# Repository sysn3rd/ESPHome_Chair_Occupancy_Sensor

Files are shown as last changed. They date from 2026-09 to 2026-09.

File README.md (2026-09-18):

# Recliner Occupancy Sensor

A pressure pad under a recliner's seat cover tells Home Assistant when someone sits down and gets up. Home Assistant then reminds a caregiver to check on them, for a bathroom trip, a change, or a stretch, before they have been sitting too long. It works while the person is asleep and completely still, which motion sensors do not.

It was built for an elderly family member who uses a lift recliner and a walker and sometimes falls asleep in the chair, cared for by someone working from home in another room.

> **Safety note.** This is an assistive reminder tool. It is not a medical device, it does not detect falls, and it is not a substitute for supervision or professional care. It can fail: power cuts, WiFi outages, phone notification settings, Home Assistant problems, or a pad that has moved. It is designed to fail loudly where it can, with alerts when the sensor goes offline or the pad is disconnected, but the caregiver remains responsible. Test it before relying on it, and keep checking it.

Wiring diagram

## What it does

- **Reminders while seated,** at an interval you set, with **Handled** and **Snooze** buttons on the phone notification.
- **Escalation** to a critical alert, which breaks through silent mode, if a reminder is ignored. An event and an optional webhook let another system, such as an assistant or pager, escalate further.
- **Quiet hours:** no reminders overnight, so nobody is woken while the person sleeps in the chair.
- **Optional alerts** when the person gets up, and after a long sit (default 4 hours, daytime only).
- **Fails loudly:** an alert if the sensor goes offline, and another if the pad cable is cut or unplugged. Without that check, a broken pad would look like an empty chair and reminders would silently stop.
- **Rides out glitches:** a WiFi drop, reboot or pad fault keeps the last known state instead of cancelling a reminder.

## How it works

- **Pad:** a replacement chair alarm pad, the kind sold for caregiver monitors. It is a membrane switch: sitting presses two conductive layers together. Many pads run each layer out and back on two wires; this project uses the spare wire to detect a broken cable.
- **Board:** a Seeed XIAO ESP32S3 running ESPHome reads the pad on two pins, filters out shifting and leaning, and reports to Home Assistant over WiFi.
- **Home Assistant:** a generated package tracks when the person sat down and got up, decides when a check is due, and sends the notifications.
- **Case:** a 3D printed case holds the board, antenna and cable splices, with strain relief, attached to the chair's base with hook-and-loop.

## What you need

A Seeed XIAO ESP32S3 with its antenna, a chair sensor pad, two 1 kΩ resistors, a USB power adapter, a 3D printed case, basic soldering tools, and Home Assistant with the companion app. Full list: [docs/bom.md](docs/bom.md).

## Quick start

1. **Print** the case: [enclosure/](enclosure/README.md).
2. **Identify** your pad's wires: [docs/identify-your-pad.md](docs/identify-your-pad.md).
3. **Generate** your configuration: `python3 generate.py`. It asks for names, your phone's notify action and your preferred hours, then writes the ESPHome config, a secrets file with fresh encryption keys, the Home Assistant package, and an `INSTALL.md` written for your setup.
4. **Build:** [docs/build-guide.md](docs/build-guide.md). Flash and test the board before soldering, and test the pad on a breadboard before making it permanent.
5. **Install and test:** follow your generated `INSTALL.md`, then [docs/testing.md](docs/testing.md).

## Documentation

| Doc | Covers |
| --- | --- |
| [docs/bom.md](docs/bom.md) | Parts, tools and software |
| [docs/identify-your-pad.md](docs/identify-your-pad.md) | Finding the switch and check wires, hands-free measuring, other pad types |
| [docs/build-guide.md](docs/build-guide.md) | Step by step build and installation |
| [docs/testing.md](docs/testing.md) | Full test plan, alerting several phones |
| [docs/use-cases.md](docs/use-cases.md) | Features, optional alerts, dashboards, your own app |
| [docs/troubleshooting.md](docs/troubleshooting.md) | WiFi, stuck readings, Home Assistant issues |
| [enclosure/README.md](enclosure/README.md) | Printing and adjusting the case |

## Repository layout

```
generate.py          configuration generator (Python 3, standard library only)
templates/           ESPHome, Home Assistant and install guide templates
examples/            example answers for generate.py --config
enclosure/           OpenSCAD source and printable STLs
docs/                build, test and usage documentation
output/              your generated files (git-ignored, contains secrets)
```

## Status

Built and in use in one home, with one pad model: the Smart Caregiver 10 x 15 in replacement chair sensor pad. The hardware, firmware and in-chair behavior are tested. The Home Assistant package passes Home Assistant's own configuration check and matches the logic of the running installation. Reports from other pads and chairs are welcome.

## License

- **Code and configuration** (`generate.py`, `templates/`, `examples/`): [MIT](LICENSE).
- **Enclosure design, documentation and images** (`enclosure/`, `docs/`, this README): [CC BY-SA 4.0](LICENSE-CC-BY-SA-4.0.md).

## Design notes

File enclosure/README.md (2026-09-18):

# Enclosure

A small PLA case for the XIAO ESP32S3, its FPC antenna, and the pad cable splices, with strain relief for both cables. About 75 x 54 x 15 mm plus a 10 mm tab for the USB cable.

| File | What |
| --- | --- |
| `base.stl` | Base. Print open side up. |
| `lid.stl` | Lid. Already flipped: prints top face down. |
| `test.stl` | Just the USB-C end of the base, for a quick fit check of your USB cable's plug. |
| `recliner_enclosure.scad` | OpenSCAD source for all of the above. |

The STLs are the exact files printed and fitted for the tested build.

## Printing

- PLA, 0.2 mm layers, no supports.
- 3 walls and 20 % infill are plenty.
- About 25 g of filament for base and lid.
- Four M3 x 8 or x 10 self-tapping screws hold the lid. Drive them until just snug.

## What is inside

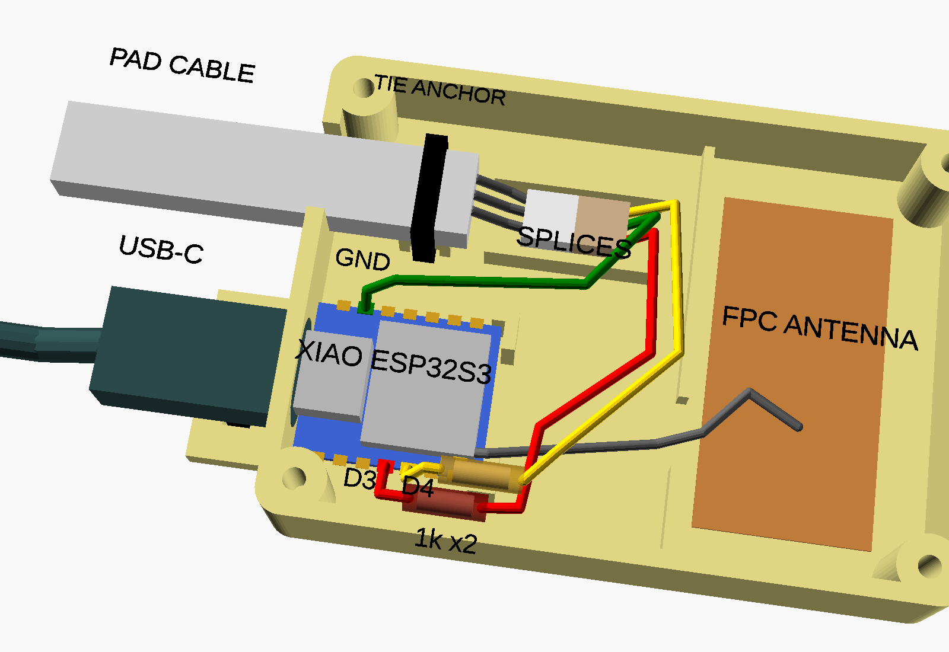
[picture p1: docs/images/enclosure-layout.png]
Inside the enclosure


- **Board bay:** the XIAO sits on a raised platform on foam tape, located by two corner stops at the antenna end, with room along both edges for wires.
- **USB-C:** a 12.5 x 7.5 mm opening sized for a cable's plug overmold, and an outside tab with two zip tie slots so a tug on the cable never reaches the board.
- **Pad cable:** an open-top notch in the end wall. Inside, a zip tie through a tunnel under a raised block grips the cable jacket, and a tongue on the lid presses lightly on the cable.
- **Splice area:** between two low rails, room for the three soldered splices (or a JST connector pair, if you prefer one).
- **Antenna bay:** the FPC antenna sticks flat to the floor, past a low divider with a gap for the coax.

## Adjusting

Open `recliner_enclosure.scad` in OpenSCAD. The `part` variable picks the view:

| `part` | Shows |
| --- | --- |
| `layout` (default) | The base with stand-in board, antenna, cables and wiring. Preview only (F5); rendering (F6) falls back to the base. |
| `assembly` | Base and lid together |
| `base`, `lid`, `test` | The printable parts |

Export a part from the command line:

```
openscad -D 'part="base"' -o base.stl recliner_enclosure.scad
```

Values you are most likely to change:

| Variable | Default | When to change |
| --- | --- | --- |
| `cable_w`, `cable_t` | 10, 5 mm | Your pad cable's width and thickness. Measure it. If only the lid's grip is wrong, change `cable_t` and reprint just the lid. |
| `cable_squeeze` | 0.3 mm | How hard the lid tongue presses on the cable. Keep it light; a crushed flat cable can short its conductors. |
| `usb_center_above_pcb_bottom`, `platform_h` | 2.7, 2.5 mm | If your USB plug does not line up with the opening. Print `test.stl` to check. |

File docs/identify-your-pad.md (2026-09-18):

# Identify your pad's wires

Do this before soldering anything. Guessing the wire pair is the most common way to end up with a sensor that reads "occupied" forever.

## What you are looking for

Chair alarm pads are membrane switches: two conductive layers that touch when someone sits. Many pads, including the tested one, run **each layer out and back on two wires** so the original alarm can check the cable is intact. That gives four wires in two loops:

| Pair | Empty pad | Someone sitting |
| --- | --- | --- |
| Both ends of layer A (tested pad: red + black) | about 0 Ω, always | about 0 Ω |
| Both ends of layer B (tested pad: green + yellow) | about 0 Ω, always | about 0 Ω |
| One wire from A, one from B (any cross pair) | open | low, tens of ohms up to a few kΩ |

The switch is the **cross pair**. The two same-layer pairs are not switches at all: they are shorts. Wiring one across D3 and GND ties the pin to ground permanently.

Wiring diagram

## Measure hands-free

Holding meter probes on thin stranded wire gives false readings: a probe that slips reads "open", which looks exactly like an open switch. Removing your hands from the measurement fixes that.

1. Cut off the pad's plug. Strip about 5 mm of each wire and twist the strands.
2. Solder or twist each pad wire onto a short solid-core jumper, and plug each into its own row of a breadboard.
3. Wrap a solid-core jumper tightly around each meter probe tip and plug those into the rows you want to measure.
4. Meter on resistance. A manual-range meter on the 20k range works well; `1` or `OL` means open.

Now measure every pair (four wires make six pairs), first with the pad empty, then pressing firmly on it or sitting on it. Write both readings down.

## Reading the results

- **Two pairs at 0 Ω empty, cross pairs open empty and low when pressed:** the looped pad above. Wire one end of layer A to D3 and the other end of layer B to D4, each through a 1 kΩ resistor, and one end of layer B to GND. D4 is the cable-break check. The fourth wire is unused.
- **Only two wires, open empty and low when pressed:** a plain switch pad. Wire one to D3 (through the resistor) and the other to GND. Then connect **D4 directly to GND** with a short wire, or the cable check will report a problem forever. Cable-break detection is not available with this pad.
- **A cross pair is low when empty and opens when pressed:** a normally closed pad. It will work, but in the generated ESPHome file change `inverted: true` to `inverted: false` under the `Pad Raw` pin.
- **Pressed reading above about 10 kΩ:** the pad is too resistive for the board's internal pull-up to read reliably. It needs a different design (an analog threshold), which this project does not cover yet.
- **Nothing changes when pressed:** press harder, or across a wider area. Membrane pads need real weight. If still nothing, the pad may be faulty.

## Tested pad, for reference

Replacement 10in x 15in Chair Sensor Pad by Smart Caregiver, UPC 812293010372 ([Amazon B01N0P2J6X](https://www.amazon.com/dp/B01N0P2J6X)), made for their TL-2100 series monitors:

- Red + black and green + yellow are the two loops.
- Red to green reads about 40 to 60 Ω under hand pressure, open when empty.

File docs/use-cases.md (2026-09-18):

# Use cases

What the generated Home Assistant package does day to day, and how to turn on the optional parts. Entity IDs use `<person>` and `<chair>` as in [testing.md](testing.md); your `INSTALL.md` has the real ones.

## Entities

| Entity | Meaning |
| --- | --- |
| `binary_sensor.<chair>_occupied` | Device reading, filtered: on shortly after sitting, off 90 s (default) after standing. Unavailable while the device is offline. |
| `binary_sensor.<chair>_pad_cable` | Problem sensor: on when the pad cable is cut or the pad unplugged. |
| `binary_sensor.<person>_seated` | Like Occupied, but holds the last known state through outages and pad faults. Use this for timing and dashboards. |
| `sensor.<person>_sat_down` | When the person last sat down. |
| `sensor.<person>_last_got_up` | When the person last got up. |
| `sensor.<person>_minutes_seated` | Minutes in the chair this sitting, 0 when up. |
| `binary_sensor.<person>_check_due` | On when a check is due. Drives the reminders. |

The timestamps survive Home Assistant restarts and device reboots. After an outage they only update if the person's state changed while the device was offline, and then they show the reconnect time.

## Reminders (main feature)

While seated, a reminder arrives each time the interval passes since sitting down or since the last **Handled**. Ignored reminders escalate to a critical alert and a `recliner_escalation` event after the escalation delay, and repeat until handled or the person gets up. Nothing fires outside your active hours; at the end of the day an active reminder clears, and next morning it starts again if still due.

Turn on with `<person> reminders enabled`. Set `<person> reminder interval` and `<person> escalation delay` to the care plan first: both start at 1 minute after installation.

**Escalating beyond the phone:** another automation, assistant or pager can listen for `recliner_escalation` (with `event_data.person`) and stand down on `recliner_escalation_resolved`. If you gave `generate.py` a webhook URL, the same escalation and stand-down are also sent there as JSON: `{"person": ..., "event": "escalation" or "resolved", "message": ...}`.

## Alert when they get up

A notification each time the person leaves the chair, for example to go and help with a walker. Turn on `<person> got up alerts enabled`.

It arrives after the off delay (default 90 s), which stops leaning forward or shifting from counting. A sensor outage or a broken pad never triggers it.

To test: sit for at least the on delay, stand, and wait for the notification. Then sit, lean forward for a few seconds, and sit back: nothing should arrive.

If the delay is too long, watch a few days of Pad Raw history to see how long shifts actually last, then re-run `generate.py` with a smaller `delayed_off` and reinstall the firmware over WiFi. This also makes reminders clear sooner.

## Time since up

No setup needed. Add `sensor.<person>_minutes_seated`, `sensor.<person>_sat_down` and `sensor.<person>_last_got_up` to a dashboard. Home Assistant shows timestamps as relative times, like "Sat down 2 hours ago".

## Long sit alert, daytime only

One notification per sitting when the person has not got up for the hours you chose (default 4), only within active hours. If a sitting passes the threshold overnight, the alert arrives when active hours start. Turn on `<person> <N> hour seated alert enabled`.

To test without waiting hours: in the generated package, temporarily change both `above:` values in the long sit automation to `1`, reload automations, sit for 2 minutes, and confirm the alert. Then change them back.

## Dashboard

Settings > Dashboards > Add dashboard, then add cards. Tile cards show state as text as well as color.

```yaml
type: vertical-stack
cards:
  - type: tile
    entity: binary_sensor.<person>_seated
    name: In the chair
  - type: tile
    entity: sensor.<person>_minutes_seated
    name: Minutes seated
  - type: tile
    entity: sensor.<person>_last_got_up
    name: Last got up
  - type: tile
    entity: binary_sensor.<chair>_pad_cable
    name: Pad
  - type: history-graph
    title: Today
    hours_to_show: 24
    entities:
      - entity: binary_sensor.<person>_seated
```

Also useful: a Logbook card filtered to `binary_sensor.<chair>_occupied` for a text list of sit and stand times, the device's WiFi Signal sensor, and tiles for the enable toggles.

## Daily totals

The History stats integration (Settings > Devices & services > Add integration > History stats) can count time seated today (type: time, entity `binary_sensor.<person>_seated`, state on) and times up today (type: count, entity `binary_sensor.<chair>_occupied`, state off). Start `{{ today_at() }}`, end `{{ now() }}`. The count includes the device reconnecting while the person is up, so treat it as approximate.

## Longer history

Home Assistant keeps detailed history for 10 days by default. Raise it in `configuration.yaml`:

```yaml
recorder:
  purge_keep_days: 60
```

`sensor.<person>_minutes_seated` also records long-term statistics, which a Statistics graph card can show indefinitely.

## Your own dashboard app

Read from Home Assistant rather than the device: it has the derived sensors, and the device's API is meant for Home Assistant.

- **Live state:** the WebSocket API, for example with the `home-assistant-js-websocket` package (`createLongLivedTokenAuth`, `createConnection`, `subscribeEntities`).
- **History:** `GET /api/history/period/<start>?filter_entity_id=binary_sensor.<person>_seated&minimal_response&no_attributes` with `Authorization: Bearer <token>`.
- **Token:** your profile > Security > Long-lived access tokens. A browser app calling Home Assistant directly needs its origin in `http: cors_allowed_origins`, and exposes the token in page code; a small local backend that holds the token is safer.
- **Accessibility:** show state in words ("In the chair, 2 h 15 min"), not color alone; announce changes with an `aria-live="polite"` region; make an offline sensor obvious ("Sensor offline, last known: seated").

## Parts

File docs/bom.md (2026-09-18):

# Bill of materials

Quantities are for one chair. Nothing here is exotic; the only part that varies between builds is the pad, so read [identify-your-pad.md](identify-your-pad.md) before buying anything else if you already have one.

## Electronics

| Part | Qty | Notes |
| --- | --- | --- |
| Seeed Studio XIAO ESP32S3 | 1 | The plain version, not the Sense. It ships with the U.FL FPC antenna, which is **required**: without it the board sees the network at about -90 dBm and cannot connect. Consider buying 2; the castellated pads lift if reworked too often. |
| Chair sensor pad, corded, 10 x 15 in | 1 | **Tested:** Replacement 10in x 15in Chair Sensor Pad by Smart Caregiver, UPC 812293010372 ([Amazon B01N0P2J6X](https://www.amazon.com/dp/B01N0P2J6X)). A replacement pad for their TL-2100 series monitors, with a 4-wire modular plug. Other brands usually work, but wire colors and layout vary: see [identify-your-pad.md](identify-your-pad.md). |
| 1 kΩ resistor, 1/4 W | 2 | One on the switch wire (D3) and one on the check wire (D4), protecting the pins from static on the long pad cable. |
| USB-C cable | 1 | Must carry data for the first flash. After that any cable works. |
| 5 V USB power adapter, 1 A or more | 1 | Wall power only. WiFi drains a battery in under a day. |
| Stranded hookup wire, 24 to 26 AWG | about 30 cm each of 3 colors | Match the pad colors if you can; it makes checking easier. |
| Heat shrink tubing | assorted, 2 to 5 mm | For every splice and over both resistors. |

## Enclosure and mounting

| Part | Qty | Notes |
| --- | --- | --- |
| PLA filament | about 25 g | Base and lid. See [../enclosure/README.md](../enclosure/README.md). |
| M3 self-tapping screws, 8 or 10 mm | 4 | Lid to base. Drive until just snug; PLA strips easily. |
| Double-sided foam tape | small piece | Holds the board on its platform. |
| Zip ties, 2.5 mm wide | 3 | One anchors the pad cable inside the case, two strain relieve the USB cable outside. |
| Adhesive hook-and-loop (Velcro) | about 5 x 7 cm | Mounts the case to the chair's base fabric. |

## Tools

| Tool | Why |
| --- | --- |
| 3D printer, or a print service | Enclosure |
| Soldering iron and solder, flux | Board and splices. Chisel tip, about 320 °C for leaded solder, 350 to 370 °C for lead-free. |
| Multimeter | Identifying the pad's wires |
| Solderless breadboard and solid-core jumper wires | Hands-free measuring and a no-solder test before the permanent build. Strongly recommended. |
| Helping hands or alligator clips | Hold work steady while soldering |
| Wire strippers, flush cutters | General |
| Computer with a USB port | First flash |

## Software

| Software | Notes |
| --- | --- |
| Home Assistant | With the companion app on each caregiver's phone |
| ESPHome | ESPHome Device Builder (add-on or desktop) or the `esphome` command line tool |
| Python 3.8 or newer | Runs `generate.py`. Standard library only, nothing to install. |

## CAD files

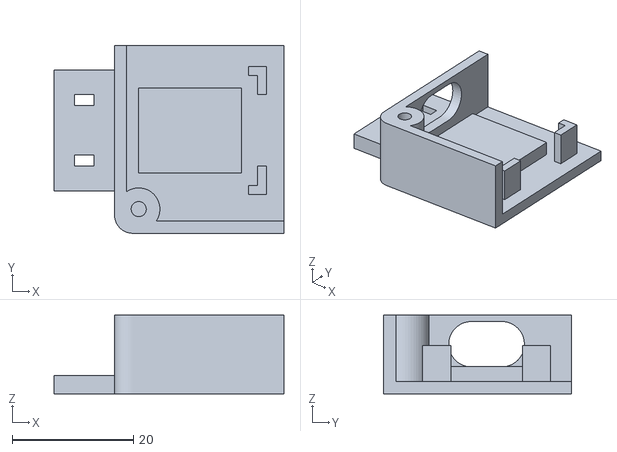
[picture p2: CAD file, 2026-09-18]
enclosure/test.stl
38.0 x 31.0 x 13.0

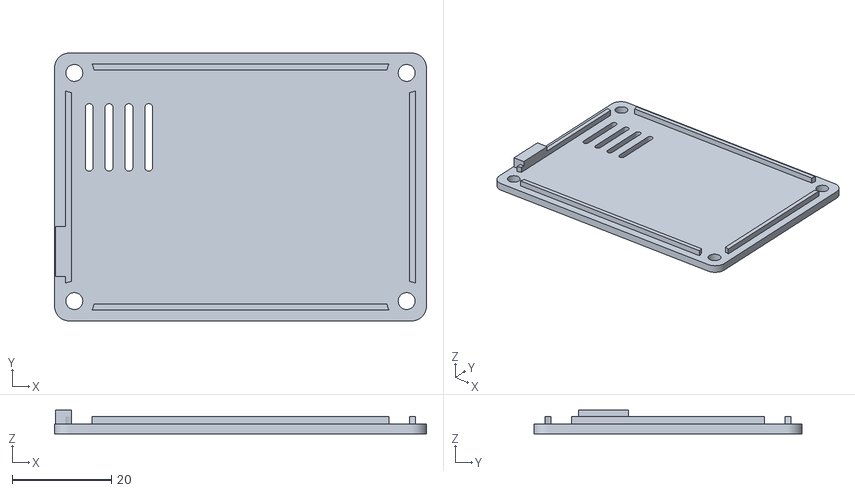
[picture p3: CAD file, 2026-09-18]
enclosure/lid.stl
75.0 x 54.0 x 4.80

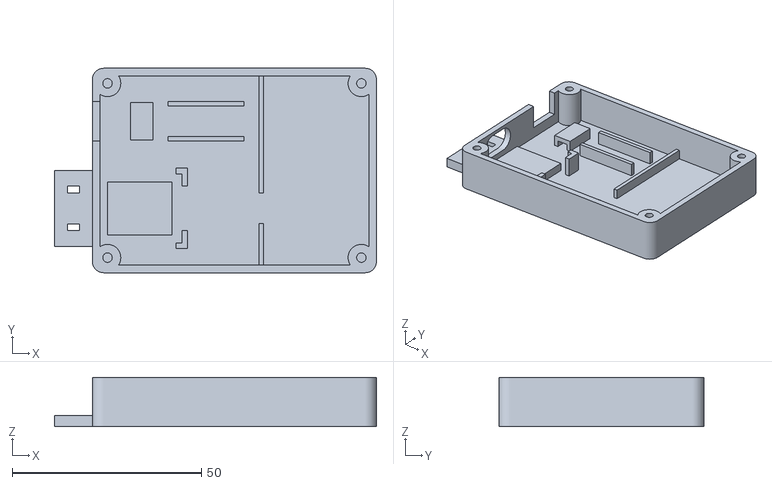
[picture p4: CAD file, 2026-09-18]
enclosure/base.stl
85.0 x 54.0 x 13.0

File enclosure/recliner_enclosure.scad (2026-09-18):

// Recliner occupancy sensor enclosure
// Seeed XIAO ESP32S3 + FPC antenna + pad cable splices (or an optional JST pair)
// License: CC BY-SA 4.0 (see LICENSE-CC-BY-SA-4.0.md)
//
// Render one part at a time:
//   openscad -D 'part="base"' -o base.stl recliner_enclosure.scad
//   openscad -D 'part="lid"'  -o lid.stl  recliner_enclosure.scad
//   openscad -D 'part="test"' -o test.stl recliner_enclosure.scad   (USB-C fit test)
//
// part="layout" shows the base with approximate stand-in parts (board, antenna,
// cables, JST, zip ties, wiring). Use Preview (F5); the stand-ins are not printed.
//
// Coordinates: origin is the inside corner of the floor at the USB-C end.
// X runs from the USB-C wall toward the antenna bay, Y across, Z up.

part = "layout"; // layout | assembly | base | lid | test
show_lid = false;     // layout view: draw the lid as a transparent ghost
show_labels = true;   // layout view: floating text labels

$fn = 48;
eps = 0.01;

// ---------- Shell ----------
wall  = 2.0;
floor_t = 2.0;
lid_t = 2.0;
in_L = 71;   // interior length (X)
in_W = 50;   // interior width (Y)
in_H = 11;   // interior height, floor top to lid underside
corner_r = 3;

// ---------- XIAO ESP32S3 ----------
pcb_L = 21.0;
pcb_W = 17.8;
pcb_gap_front = 0.3;   // PCB edge to inside of USB wall
pcb_y = 15;            // PCB centerline in Y
platform_h = 2.5;      // raised pad the board sits on
tape_t = 1.0;          // double-sided foam tape under the board
locator_h = 2.5;       // how far corner locators rise above the board bottom

// USB-C opening, sized for a cable overmold, not the bare receptacle
usb_open_w = 12.5;
usb_open_h = 7.5;
usb_center_above_pcb_bottom = 2.7;  // from the Seeed case: port sits ~1.1 above floor, ~3.2 tall

// ---------- Pad cable and JST ----------
cable_w = 10.0;        // measure with calipers
cable_t = 5.0;
cable_y = 38;          // cable centerline in Y
cable_clear = 0.4;     // added to each notch dimension
cable_squeeze = 0.3;   // lid tongue presses this far into the jacket
anchor_x = 8;          // zip tie anchor block start
anchor_len = 6;
anchor_h = 3.5;        // cable rides on top of this block
tie_tunnel_w = 3.5;    // for 2.5 mm zip ties
tie_tunnel_h = 2.0;

jst_gap = 8.0;         // space between cradle rails: holds the three soldered splices or a JST pair
jst_x0 = 18;
jst_len = 20;
jst_rail_t = 1.2;
jst_rail_h = 4;

// ---------- Antenna bay ----------
rib_x = 42;
rib_t = 1.2;
rib_h = 3;
rib_gap = 8;           // U.FL cable passes here, centered on pcb_y

// ---------- Lid screws (M3 self-tapping into PLA) ----------
boss_d = 7;
boss_inset = 2;        // boss center from inside corner
pilot_d = 2.5;
screw_clear_d = 3.4;
lip_h = 1.5;
lip_t = 1.2;
lip_clear = 0.25;

// ---------- USB cable tie tab ----------
tab_len = 10;
tab_w = 20;
tab_t = 3;
tie_slot = [3.2, 1.8];  // X (band width), Y (band thickness)
tie_slot_offset = 5;    // slot centers from the USB centerline
tie_groove_d = 1.5;

// ---------- Helpers ----------
module rounded_box(size, r) {
    hull() for (x = [r, size[0] - r], y = [r, size[1] - r])
        translate([x, y, 0]) cylinder(r = r, h = size[2]);
}

boss_pts = [[boss_inset, boss_inset], [boss_inset, in_W - boss_inset],
            [in_L - boss_inset, boss_inset], [in_L - boss_inset, in_W - boss_inset]];

usb_z = platform_h + tape_t + usb_center_above_pcb_bottom;
notch_bottom = anchor_h;
tongue_bottom = anchor_h + cable_t - cable_squeeze;

// ---------- Base ----------
module shell() {
    difference() {
        translate([-wall, -wall, -floor_t])
            rounded_box([in_L + 2 * wall, in_W + 2 * wall, floor_t + in_H], corner_r);
        cube([in_L, in_W, in_H + eps]);
    }
}

module usb_cut() {
    translate([-wall - eps, pcb_y, usb_z])
        rotate([0, 90, 0])
        hull() for (dy = [-(usb_open_w - usb_open_h) / 2, (usb_open_w - usb_open_h) / 2])
            translate([0, dy, 0]) cylinder(d = usb_open_h, h = wall + 2 * eps);
}

module cable_notch() {
    translate([-wall - eps, cable_y - (cable_w + cable_clear) / 2, notch_bottom])
        cube([wall + 2 * eps, cable_w + cable_clear, in_H]);
}

module board_platform() {
    translate([2, pcb_y - 7, 0]) cube([pcb_L - 4, 14, platform_h]);
}

module box2(a, b) {  // cube between two corner points
    translate([min(a[0], b[0]), min(a[1], b[1]), min(a[2], b[2])])
        cube([abs(b[0] - a[0]), abs(b[1] - a[1]), abs(b[2] - a[2])]);
}

// L-shaped stops at the two corners away from the USB-C port.
// They touch only the last ~1.5 mm of each long edge, clear of the castellated pads.
module board_locators() {
    top = platform_h + tape_t + locator_h;
    back = pcb_gap_front + pcb_L + 0.3;
    for (s = [-1, 1]) {
        edge = pcb_y + s * (pcb_W / 2 + 0.2);
        box2([back, pcb_y + s * (pcb_W / 2 - 3), 0], [back + 1.5, edge + s * 1.5, top]);
        box2([back - 1.5, edge, 0], [back + 1.5, edge + s * 1.5, top]);
    }
}

module tie_anchor() {
    difference() {
        translate([anchor_x, cable_y - cable_w / 2, 0])
            cube([anchor_len, cable_w, anchor_h]);
        translate([anchor_x + (anchor_len - tie_tunnel_w) / 2, cable_y - cable_w / 2 - eps, -eps])
            cube([tie_tunnel_w, cable_w + 2 * eps, tie_tunnel_h + eps]);
    }
}

module jst_cradle() {
    for (s = [-1, 1])
        translate([jst_x0, cable_y + s * (jst_gap / 2) + (s > 0 ? 0 : -jst_rail_t), 0])
            cube([jst_len, jst_rail_t, jst_rail_h]);
}

module antenna_rib() {
    difference() {
        translate([rib_x, 0, 0]) cube([rib_t, in_W, rib_h]);
        translate([rib_x - eps, pcb_y - rib_gap / 2, -eps]) cube([rib_t + 2 * eps, rib_gap, rib_h + 2 * eps]);
    }
}

module bosses() {
    for (p = boss_pts) translate([p[0], p[1], 0])
        difference() {
            cylinder(d = boss_d, h = in_H);
            translate([0, 0, 2]) cylinder(d = pilot_d, h = in_H);
        }
}

// Floor-level tab outside the USB-C wall. Zip tie the power cable here so a tug
// never reaches the XIAO's USB-C receptacle.
module usb_tie_tab() {
    slot_x = -wall - tab_len / 2;
    difference() {
        translate([-wall - tab_len, pcb_y - tab_w / 2, -floor_t])
            cube([tab_len + eps, tab_w, tab_t]);
        for (s = [-1, 1])
            translate([slot_x - tie_slot[0] / 2, pcb_y + s * tie_slot_offset - tie_slot[1] / 2, -floor_t - eps])
                cube([tie_slot[0], tie_slot[1], tab_t + 2 * eps]);
        // underside groove so the tie band stays flush with the Velcro
        translate([slot_x - tie_slot[0] / 2, pcb_y - tie_slot_offset - tie_slot[1] / 2, -floor_t - eps])
            cube([tie_slot[0], 2 * tie_slot_offset + tie_slot[1], tie_groove_d + eps]);
    }
}

module base() {
    difference() {
        union() {
            shell();
            bosses();
            board_platform();
            board_locators();
            tie_anchor();
            jst_cradle();
            antenna_rib();
            usb_tie_tab();
        }
        usb_cut();
        cable_notch();
        // keep pilot holes open where bosses meet the shell
        for (p = boss_pts) translate([p[0], p[1], 2]) cylinder(d = pilot_d, h = in_H);
    }
}

// ---------- Lid ----------
// Modeled in place (underside at z = in_H). Flipped for printing in "lid" mode.
module lid() {
    difference() {
        union() {
            translate([-wall, -wall, in_H])
                rounded_box([in_L + 2 * wall, in_W + 2 * wall, lid_t], corner_r);
            // locating lip just inside the walls
            difference() {
                translate([lip_clear, lip_clear, in_H - lip_h])
                    cube([in_L - 2 * lip_clear, in_W - 2 * lip_clear, lip_h + eps]);
                translate([lip_clear + lip_t, lip_clear + lip_t, in_H - lip_h - eps])
                    cube([in_L - 2 * (lip_clear + lip_t), in_W - 2 * (lip_clear + lip_t), lip_h + 3 * eps]);
                for (p = boss_pts) translate([p[0], p[1], in_H - lip_h - eps])
                    cylinder(d = boss_d + 1, h = lip_h + 3 * eps);
            }
            // tongue that fills the cable notch and clamps the jacket
            translate([-wall + 0.2, cable_y - (cable_w + cable_clear) / 2 + 0.2, tongue_bottom])
                cube([wall - 0.2 + lip_clear + lip_t, cable_w + cable_clear - 0.4, in_H - tongue_bottom + eps]);
        }
        for (p = boss_pts) translate([p[0], p[1], in_H - lip_h - 1])
            cylinder(d = screw_clear_d, h = lid_t + lip_h + 2);
        // vent slots over the board
        for (i = [0 : 3])
            translate([5 + i * 4, pcb_y - 6, in_H - eps])
                hull() for (dy = [0, 12]) translate([0, dy, 0]) cylinder(d = 1.6, h = lid_t + 2 * eps);
    }
}

// ---------- USB-C fit test ----------
// Prints the USB end wall, platform and locators only. Check the plug seats fully.
module test_piece() {
    intersection() {
        base();
        translate([-wall - tab_len - 1, -wall - 1, -floor_t - 1]) cube([wall + tab_len + 27, 32, in_H + floor_t + 2]);
    }
}
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

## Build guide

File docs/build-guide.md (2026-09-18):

# Build guide

Order matters: prove each stage works before making anything permanent. Flash and test the board before soldering the pad, and test the pad on a breadboard before soldering it to the board.

Parts and tools: [bom.md](bom.md).

## 1. Print the enclosure

Print `enclosure/base.stl` and `enclosure/lid.stl` in PLA with no supports. Details and adjustable dimensions are in [../enclosure/README.md](../enclosure/README.md). If you are unsure about your printer's tolerances, print `test.stl` first: it is only the USB-C end, and shows whether your cable's plug seats fully.

## 2. Identify the pad's wires

Follow [identify-your-pad.md](identify-your-pad.md). You need to know three wires by the end:

| Role | Tested pad | Board pin |
| --- | --- | --- |
| Switch wire (one end of layer A) | red | D3, through the 1 kΩ resistor |
| Return wire (one end of layer B) | green | GND |
| Check wire (other end of layer B) | yellow | D4, through a second 1 kΩ resistor |
| Unused (other end of layer A) | black | none, insulate |

## 3. Generate your configuration

```
python3 generate.py
```

It asks for the person's name, the chair's name, your phone's notify action (find it in Home Assistant under Developer tools > Actions by typing `notify.mobile_app`), the hours when alerts are allowed, and a few timings. Press Enter to accept a default. Files are written to `output/<name>/`, along with an `INSTALL.md` that uses your names throughout. Keep `answers.json`: re-running with `--config` changes settings without changing your encryption keys.

## 4. Flash and add the board, before any soldering

1. Clip the FPC antenna onto the XIAO's U.FL socket: line it up square, press straight down until it clicks. Do this unpowered. It is only rated for about 30 connections, so attach it once and leave it.
2. Follow sections 1 and 2 of your generated `INSTALL.md` to flash the board and add it to Home Assistant.
3. **Jumper test.** Touch a wire between D3 and GND for 20 seconds, then remove it. In Home Assistant, `Pad Raw` turns on immediately, `Occupied` turns on after the delay you chose (default 10 s), and `Occupied` turns off after the release delay (default 90 s). `Pad Cable` shows Problem at this stage, because nothing is on D4 yet. That is expected.

If the board does not join WiFi, check the antenna first. See [troubleshooting.md](troubleshooting.md).

## 5. Test the pad on a breadboard

Before soldering, wire the pad to the board through the breadboard: switch wire to D3 and check wire to D4, each through a resistor, and return wire to GND. Then, watching Home Assistant:

1. Pad empty: `Pad Raw` off, `Pad Cable` OK.
2. Press the pad: `Pad Raw` on, `Occupied` on after the delay.
3. Release: `Occupied` off after the release delay.
4. Pull the check wire or the return wire: `Pad Cable` shows Problem within 2 seconds. Put it back.

If any step fails, stop and see [troubleshooting.md](troubleshooting.md). Everything after this point is harder to undo.

## 6. Solder the permanent wiring

Unplug the USB cable first.

1. **Board wires.** Solder three short hookup wires to the XIAO: one to D3, one to D4, one to GND. D3 and D4 sit next to each other on one edge; GND is on the opposite edge, second from the USB-C end. Confirm against the labels printed on your board. Tin the pad and the wire first, then join them with a 2 to 3 second touch. Lingering lifts pads.
2. **Resistors.** Splice a 1 kΩ resistor into the D3 wire and another into the D4 wire, with heat shrink over each joint and each resistor body.
3. **Splices to the pad.** Slide heat shrink on first, then splice each pad wire to its board wire. Keep the joints staggered so they cannot touch each other, and shrink the tubing over each.
4. **Unused wire.** Trim it and cover the end with heat shrink so it cannot touch anything.
5. Plug in and repeat the four breadboard checks from step 5.

If fine motor work is difficult, clamp everything in helping hands or alligator clips so neither hand holds the work, and pre-tin every wire before joining. Soldered splices are more forgiving than crimped connectors: the JST PH crimp terminals this enclosure was first drawn for are small and fiddly, and the splices fit in the same space.

## 7. Assemble

Inside the enclosure

1. **Board:** foam tape on the raised platform, board pressed down with the USB-C port square in its opening. The two corner stops at the far end set its position.
2. **Antenna:** peel and stick flat to the floor of the antenna bay, beyond the low divider. Run the coax through the gap in the divider without kinking it.
3. **Pad cable:** lay the cable in the open notch in the end wall so it rides on top of the anchor block. Thread a zip tie through the tunnel under the block and around the cable. **Snug, not crushing**: the cable should not slide, but a flat cable crushed hard can short its conductors.
4. **Splices:** lay them between the two rails, away from the screw posts.
5. **Power cable:** plug in, then zip tie the cable to the tab outside the USB end using its two slots, so a tug never reaches the board's connector.
6. **Lid:** lower it straight down, check no wire is pinched at the rim, and drive the four screws until just snug.
7. Stick the hook-and-loop to the underside.

## 8. Install at the chair

- **Pad:** under the seat cover, flat, where the person actually sits. It must not bridge the fold between seat and backrest.
- **Case:** on the back of the chair's base fabric, on a part that does not move with the lift or recline mechanism.
- **Cables:** leave slack for the full lift and recline travel, and route both cables away from the scissor mechanism and footrest hinge.
- **WiFi:** check the device's `WiFi Signal` sensor at the chair. Better than -70 dBm is solid; worse than -80 dBm is risky.

## 9. Home Assistant and testing

Follow sections 3 to 5 of your `INSTALL.md`, then work through [testing.md](testing.md) completely before relying on it.

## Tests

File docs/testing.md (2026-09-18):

# Testing

Run all of this before relying on the sensor. A reminder that silently fails to arrive is the failure this project exists to prevent, and most of the ways that can happen are in Home Assistant and phone settings, not the hardware.

Names below use `<person>` for your person ID (for example `grandma`) and `<chair>` for your chair ID (for example `recliner`). Your generated `INSTALL.md` has the exact entity IDs. Tests with timings must run inside your active hours (default 09:00 to 22:00).

## Before you start

1. **Notify action works.** Developer tools > Actions, run your notify action with a test message. It must arrive on the phone.
2. **Critical alerts allowed** (iOS): Settings > Notifications > Home Assistant > Critical Alerts on.
3. **Short timings:** set `<person> reminder interval` to 2 and `<person> escalation delay` to 1. Turn on `<person> reminders enabled`.
4. **Watch events:** in a browser tab, Developer tools > Events, listen to `recliner_escalation`, and in another tab `recliner_escalation_resolved`.

## 1. Device

| Action | Expected |
| --- | --- |
| Sit on the pad | `binary_sensor.<chair>_pad_raw` on immediately, `binary_sensor.<chair>_occupied` on after the on delay, `binary_sensor.<person>_seated` on |
| Shift, lean forward, recline, use the lift | Occupied stays on. Pad Raw may flicker; that is what the filter is for |
| Stand up | Occupied off after the off delay (default 90 s) |
| Drop into the chair hard, the way the person does | Occupied on after the on delay, no bounce |

## 2. Reminder cycle

Sit and leave the phone alone.

| Time after sitting | Expected |
| --- | --- |
| about 2 min | "Time to check on `<Person>`" notification with Handled and Snooze buttons |
| about 3 min | Critical "`<Person>` check overdue" alert, and a `recliner_escalation` event |
| every minute after | Reminder, then escalation, repeating |

## 3. Each way out

| Action | Expected |
| --- | --- |
| Tap **Handled** | Notification clears, `recliner_escalation_resolved` fires, next reminder about 2 min later if still seated |
| Tap **Snooze** | Notification clears, no reminder until the snooze ends |
| Stand up mid-cycle | After the off delay, notification clears and `recliner_escalation_resolved` fires |
| Turn off reminders enabled mid-cycle | Notification clears |

## 4. Offline

| Action | Expected |
| --- | --- |
| Unplug the device for 3 minutes | "sensor offline" alert |
| Unplug while seated with a reminder active | `binary_sensor.<person>_seated` stays on and reminders keep coming |
| Then stand up, plug back in | Seated turns off once the device reconnects |

## 5. Pad cable fault

| Action | Expected |
| --- | --- |
| While seated, disconnect the check wire (D4) or the return wire | `binary_sensor.<chair>_pad_cable` on within 2 s, "pad disconnected" alert about 10 s later, Seated stays on, no "got up" alert |
| Reconnect | Pad Cable clears, `sensor.<person>_sat_down` keeps its original time |

## 6. Optional alerts

If you enabled them, test the got up alert and the long sit alert as described in [use-cases.md](use-cases.md).

## 7. Real settings

Set the reminder interval and escalation delay to the care plan, keep reminders enabled, and watch a few days of `binary_sensor.<chair>_pad_raw` history. You are checking that the pad reads reliably where the person actually sits, including when asleep and still.

## Alerting more than one phone

Create a notify group in `configuration.yaml`, restart, then re-run `python3 generate.py --config output/<person>/answers.json` after changing `notify_action` in that file to `notify.family_phones`:

```yaml
notify:
  - platform: group
    name: family_phones
    services:
      - action: mobile_app_first_phone
      - action: mobile_app_second_phone
```

Titles, messages, buttons and clearing all pass through to every phone in the group. Older Home Assistant versions use `service:` instead of `action:` in the group entries.

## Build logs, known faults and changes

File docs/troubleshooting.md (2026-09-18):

# Troubleshooting

## WiFi

**Device never joins the network; logs show the network at -85 to -96 dBm and "Auth Expired" or "Probe Request Unsuccessful".** The FPC antenna is not attached. The XIAO ESP32S3 has no usable antenna without it. Unplug, press the antenna's U.FL plug straight down onto the socket until it clicks, and power up again. Typical signal with it attached: -50 to -65 dBm.

**Device creates a "<Chair> Fallback" network.** It could not join your WiFi. Check the antenna, that the network is 2.4 GHz, and the name and password in `secrets.yaml`. You can join the fallback network from a phone (password is in `secrets.yaml`) to enter WiFi details.

**Signal worse than about -75 dBm at the chair.** Move the case to a different side of the chair, keep the antenna flat and away from the metal frame, or add a closer access point.

## Flashing

**Board not detected over USB.** Use a data cable, not a charge-only one. Unplug, hold the BOOT button, plug in, then release.

## Pad readings

**Occupied (and Pad Raw) stuck on with nobody in the chair.** Almost always both ends of the same conductor are wired to D3 and GND, which ties D3 to ground. Re-identify the wires with [identify-your-pad.md](identify-your-pad.md). To split the problem, unplug the board, disconnect the GND wire, and power up again: if Pad Raw goes off, the short is in the pad or cable; if it stays on, look for a solder bridge on the board. Also check for a zip tie crushing the pad cable.

**Occupied never turns on.** The wire pair is wrong, the pad is normally closed (see [identify-your-pad.md](identify-your-pad.md)), the resistor joint is broken, or the pad needs more weight in that spot. Watch Pad Raw while pressing firmly.

**Pad Raw flickers while seated.** Normal in small amounts; the Occupied filter absorbs it. Constant flicker means the pad sits where the person only partly rests: move it to where they actually land, flat and clear of the seat and backrest fold.

**Pad Cable always shows Problem.** D4 is not connected, or it is connected to the wrong conductor. The check wire must be the other end of the same conductor as the GND wire. For a two-wire pad, connect D4 straight to GND.

**Meter readings jump around.** Probes on thin stranded wire give unreliable contact, and a slipping probe reads "open". Use the breadboard method in [identify-your-pad.md](identify-your-pad.md), or clip the probes on.

## Home Assistant

**Entity IDs end in `_2`.** An older device with the same name is still registered, for example after swapping boards. Delete the old device's ESPHome entry, then re-add the new one.

**After replacing the board, Home Assistant still shows the old one as unavailable.** The integration remembers the old board's address and hardware ID. Use Reconfigure on the ESPHome entry with host `<device>.local`, or delete the entry and add it again with the same encryption key.

**Check configuration reports errors in the package.** Re-generate it rather than editing by hand; the generator validates your answers. If you edited the file, compare with a fresh copy.

**No notifications at all.** Test the notify action alone from Developer tools > Actions. If that fails, the action name is wrong or the companion app is not registered. Every alert in the package uses the same action.

**Reminders arrive but the critical alert is silent.** iOS: allow Critical Alerts for the Home Assistant app. Android: set the `<person>_urgent` notification channel to high importance with sound; the channel appears after the first escalation.

**Nothing happens in the evening or early morning.** Reminders and the long sit alert only run within active hours (default 09:00 to 22:00). This is intentional, so nobody is woken while the person sleeps in the chair.

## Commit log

2026-09-18 Initial public release of the recliner occupancy sensor
    Enclosure (OpenSCAD source and the printed STLs), wiring diagram, parts
    list, pad identification guide, build guide, test plan, use cases and
    troubleshooting, plus generate.py: a standard-library Python generator
    that writes a personalized ESPHome config, secrets with fresh keys, a
    Home Assistant package and an install guide.
    Generated ESPHome configs validate with ESPHome 2026.9.0, and generated
    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
    [base.stl, lid.stl, recliner_enclosure.scad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]
2026-09-18 Add the 1 kOhm resistor on the check wire (D4)
    The tested build has a resistor on both pad inputs, protecting D3 and
    D4 from static on the long pad cable. Show it in the wiring diagram and
    enclosure render, list two resistors in the parts list, and update the
    build and pad guides. Also fix the ESPHome template's pointer to the
    wiring diagram.
    [recliner_enclosure.scad]
2026-09-18 Draw the wiring diagram with the board's real pin layout
    Show the XIAO component side up with USB-C at the bottom and all 14
    pins in place: D3 and D4 near the middle of the right edge, GND second
    from the USB end on the left edge. Red and yellow now route over the
    top of the board to reach D3 and D4, and unused pins are greyed out.
